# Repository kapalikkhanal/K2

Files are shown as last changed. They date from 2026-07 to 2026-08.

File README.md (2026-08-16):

# K2

A 3D-printed 12-DOF bipedal robot that **stands and marches in place** under a
reinforcement-learning policy, with a MuJoCo digital twin generated from the
Fusion 360 CAD export. A separate heading-aware policy provides low-speed
forward walking in the twin.

| | |
|---|---|
| DOF | 12 revolute — 6 per leg (hip pitch / roll / yaw, knee, ankle pitch / roll) |
| Actuators | 12× Feetech STS3215, 30 kg·cm @ 12 V (2.94 N·m, 4.712 rad/s) |
| Measured / modeled mass | 1.280 kg / 1.280 kg |
| Hip height (straight pose) | 336 mm |
| Foot-site stance width (straight pose) | 68 mm |
| Controller | Raspberry Pi 5 (policy inference 0.012 ms/tick on one CPU thread) |
| IMU | LSM6DS3, inside the electronics tray |
| Control rate | 50 Hz (2 ms physics × decimation 10) |

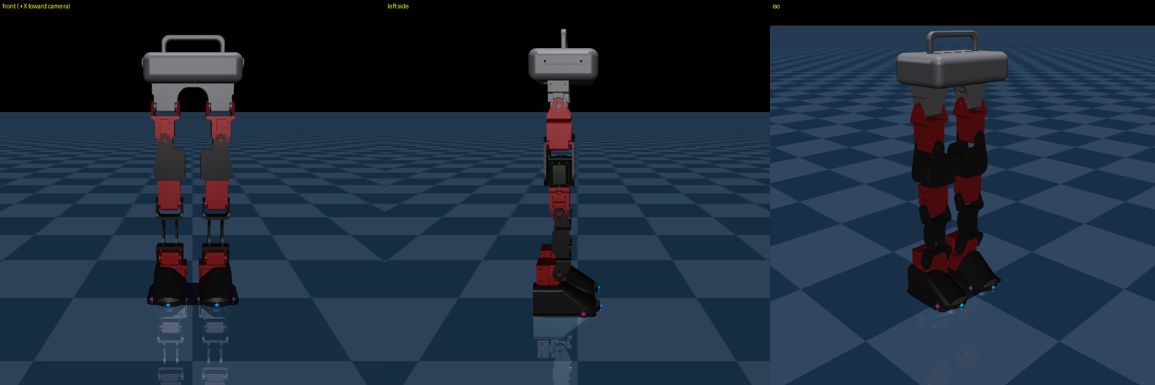
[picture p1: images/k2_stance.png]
K2 stance


## Scope

This repository covers **hold**, **march**, and a separate low-speed,
command-conditioned forward-walking task.

## Layout

```
k2_rl/            mjlab RL task: hold + march, PPO, ONNX export
hardware/         unified sim <-> real control stack (one code path)
policies/         trained policy, ready to deploy
mjcf/             MuJoCo model (generated)
urdf/             Fusion export + mass/limit-corrected URDF (generated)
meshes/K2/        visual .obj + convex collision .stl
scripts/          CAD -> URDF -> MJCF pipeline
docs/             link-to-link transformation matrices
robot.md          complete reference: joints, calibration, twin, deployment
```

Generated files are checked in, so the model and policy work without re-running
anything.

## Quick start

Run the trained policy in the twin:

```bash
python -m hardware.k2_policy_run --bus sim --viewer --mode march \
  --policy policies/march_hold_v4_1999.onnx

python -m hardware.k2_policy_run --bus sim --viewer --mode walk \
  --forward-speed 0.01 --policy policies/forward_walk_v1_iter950.onnx
```

On the real robot (from the Pi):

```bash
python -m hardware.k2_policy_run --bus /dev/ttyAMA0 --mode hold \
  --policy policies/march_hold_v4_1999.onnx
python -m hardware.k2_policy_run --bus /dev/ttyAMA0 --mode march \
  --march-after 5 --duration 20 --slew 1.0 --fall-angle 10 \
  --policy policies/march_hold_v4_1999.onnx --log run.csv
```

Torque release is retried and verified from every servo register on exit,
including Ctrl-C. `--slew` caps per-tick joint motion and `--fall-angle` cuts
torque above a torso tilt.

## Training

Needs [mjlab](https://github.com/mujocolab/mjlab) and a CUDA GPU.

```bash
python -m k2_rl.train Mjlab-InPlace-K2 --env.scene.num-envs 4096 \
  --agent.max-iterations 2000 --agent.run-name march_v4
python -m k2_rl.play  Mjlab-InPlace-K2       --checkpoint-file <run>/model_2000.pt
python -m k2_rl.play  Mjlab-InPlace-March-K2 --checkpoint-file <run>/model_2000.pt
python -m k2_rl.export_onnx --checkpoint <run>/model_2000.pt
```

Both task IDs share one checkpoint — the first plays it holding, the second
marching. `export_onnx` bakes the joint names, default pose and action scale
into the ONNX so the deploy script stays correct across retrains.

## The sim <-> real abstraction

The same program drives MuJoCo or the real servo chain by changing one flag.
The seam is the **servo bus, in raw encoder counts** — the robot's actual wire
language. Everything above it (calibration, count<->rad, observation building,
clamping, slew limiting, control rate) is identical code on both paths.

```bash
python -m hardware.k2_ctrl --bus sim --motion squat --viewer
python -m hardware.k2_ctrl --bus /dev/ttyAMA0 --motion squat
```

## Rebuilding the model from CAD

```bash
python scripts/phase1_mass.py       # -> urdf/K2_phase1.urdf
python scripts/phase2_make_mjcf.py  # -> mjcf/k2_physics.xml
python scripts/phase3_validate.py   # mass, limits, contact, torque
MUJOCO_GL=egl python scripts/render_check.py   # -> images/
python -c "from hardware import k2_conventions as C; C.write_joint_limits()"
```

## Conventions worth knowing before you change anything

- Robot faces world **+X**, **+Y is the robot's own LEFT**, **+Z** is up. This is
  forced: MuJoCo is right-handed, so with +x forward and +z up, +y is left.
- **The MJCF bodies named `*_right` sit at +y, i.e. on the robot's own LEFT.**
  Fusion named them from the viewer's side. `JOINT_TO_ID` accounts for this — read
  the leg-mapping note in `hardware/k2_conventions.py` before touching it.
- The IMU chip frame is not the root or MJCF `imu` site frame.
  `k2_attitude.py` uses the hardware-measured chip -> root -> site transforms;
  held forward/right tilts and a dynamic gyro/gravity consistency test validate
  the signs.
- Collision is **feet only**, so the legs cannot snag on their own shells.
- Timestep is **2 ms**. At 5 ms the foot-ground contact injects energy and the
  robot bounces higher than it was dropped from.
- Every hinge carries `armature=0.01` (STS3215 reflected rotor inertia). Without
  it the resting IMU reading chatters over [-1.8, 24.6] m/s^2 instead of 9.81.
- Joint limits are read from the MJCF into `hardware/joint_limits.json` — never
  hardcoded, so they cannot drift from the model.

## Status

Hold is solid. The calibrated march completed 27 continuous unsupported seconds
on hardware (after a 3 s hold), with a 12.54 deg exact logged peak against a
14 deg cutoff. The gait is stable but still has limited tilt margin and a
roughly 1.8 deg mean physical-left bias. Roll remains a geometric budget (stance
width vs CoM height), not merely a reward-tuning knob.

All five left/right sole reward sites now mirror within 0.001 mm. These sites do
not change collision geometry; their symmetry prevents the gait rewards from
teaching a lateral bias.

The forward-walk checkpoint `forward_walk_v1_iter950.onnx` is trained over
0.01--0.04 m/s with foam-compatible friction randomization. Nominal 20 s twin
tests produce 10.1--10.6 mm minimum full-sole swing clearance across that speed
range, no foot collisions, and at most 4.5 deg peak torso tilt. It has not yet
been validated unsupported on hardware.

See `robot.md` for the full reference and `k2_rl/README.md` for the task design.

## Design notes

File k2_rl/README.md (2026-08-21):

# k2_rl — RL locomotion for the K2 biped (mjlab)

Closed-loop RL locomotion for the 12-DOF K2. The original policy switches
between two behaviours **in place** (zero net translation):

- **hold** — stand still on both feet, stay upright, reject pushes (IMU feedback).
- **march** — step in place, alternating feet.

`Mjlab-Forward-K2` is a separate low-speed task. It retains hold/march balance
and adds a commanded forward speed in the initial 0.01--0.04 m/s range. Its
training randomizes sole height/angle, friction, actuator latency, and dynamics.

`Mjlab-Bidirectional-K2` is the conservative signed-speed successor. It trains
from scratch over -0.04--+0.04 m/s, keeps hold at the captured default crouch,
ramps both gait activation and velocity commands to prevent transition jerk,
and randomizes up to 5 mm unequal support, ±1.5° sole mounting, and light pushes.
Hold deliberately uses the previously proven learned support stance; it is not
forced into the narrower captured crouch because that variant fell in the twin.
The signed range is ±0.05 m/s, with a 0.8 s gait blend and 0.06 m/s² command
ramp for gentler hold/walk and forward/backward transitions.
Each gait begins at the v5 double-support crossing. Hold uses paired-joint
symmetry without forcing the exact default crouch, and walking hip-pitch
antisymmetry uses weight −4.

`Mjlab-Turn-K2` adds **one** thing to the bidirectional task: a commanded body
yaw rate. The command is `vx + wz` only -- there is no lateral (vy) channel.
Every term it changes is written so that with `wz == 0` it is *identical* to its
bidirectional predecessor, which is what makes warm-starting from a working
bidirectional checkpoint safe:

| bidirectional term | turning replacement | why |
|---|---|---|
| `base_heading_error` (world +X) | `heading_reference_error` | follow the *commanded* heading |
| `base_lateral_position_l2` (world +Y spawn line) | `lateral_path_deviation_l2` | corridor turns with the command |
| `base_yaw_rate_l2` (all yaw) | `yaw_rate_error_l2` | damp only yaw the command did not ask for |
| `track_angular_velocity` (twist, pinned to 0) | `track_yaw_rate_exp` | yaw target comes from the gait command |
| `heading_sin_cos` observation | `heading_error_sin_cos` | keep the feature near zero at any commanded yaw |
| `feet_lateral_vel_l2` (world Y) | `feet_lateral_vel_body_l2` | "sideways" is a body direction once you may turn |

`GaitCommand` integrates a **reference pose** (`heading_ref`, `pos_ref`) from the
commands it emits; those terms measure against it. With no yaw channel the
reference never rotates and never leaves the environment-origin line, so each
expression collapses to exactly its predecessor -- verified numerically to 0.0
max absolute difference. Deployment reproduces the same reference by integrating
the same emitted numbers, so this needs no extra sensing on the Pi.

Two further protections keep the straight gait from decaying: `rel_turning_envs`
gives 40% of resamples an exactly-zero yaw command (uniform sampling would make
straight walking measure-zero), and the hip-pitch antisymmetry penalty fades with
commanded yaw, because a turning gait is genuinely asymmetric. Hip-yaw pose
tolerance widens from 0.12 to 0.25 rad -- it is the steering joint; foot crossing
stays guarded by the unchanged inner-edge clearance and self-collision penalties.
Trained range is a deliberately conservative +/-0.25 rad/s with a 0.30 rad/s^2
command ramp.

`Mjlab-Full-K2` is isolated in `full_env_cfg.py`. It trains body-frame forward,
backward, left/right, and yaw-rate commands from scratch; it does not alter the
working forward-only policy interface.

The `march` bit is a per-episode command the policy observes (a fraction of envs
march, the rest hold), so a single trained policy does both — flip the bit at run
time. This is a closed balance-feedback loop: the policy reads the IMU every
tick and actively corrects lean and drift
(`robot.md` §10).

Built on mjlab's velocity-locomotion machinery, closely mirroring the Unitree G1
task (both are 6-DOF legs now), but written fresh — **never edit mjlab
site-packages**.

## Environment

Use the **`unitree_sim_env`** conda env (torch 2.7.0+cu128 with Blackwell/sm_120
GPU support + mjlab). The base env's torch does **not** support this GPU.

```bash
conda activate unitree_sim_env
cd ~/K2
```

## Package layout

| file | what |
|---|---|
| `k2_constants.py` | K2 `EntityCfg`: STS3215 position actuators (kp=20, kd=0.5 — same as `hardware/k2_bus.py`, so zero sim-to-real actuator gap), validated symmetric crouch keyframe, per-DOF regex patterns. |
| `mdp/gait_command.py` | `GaitCommand` — emits `[march, sin, cos]` plus optional signed forward speed and yaw rate, and integrates the reference pose those tasks measure against. |
| `mdp/rewards.py` | gait-aware rewards: `gait_contact`, `gait_swing`, `feet_planted`, `base_height_l2`. |
| `inplace_env_cfg.py` | the task: flat ground, zero-twist (stay in place), proprio-only actor obs (gyro + gravity + joints + gait — what the Pi can supply), domain randomization. |
| `forward_env_cfg.py` | 1--4 cm/s forward extension; heading feedback, foam-friction randomization, and full-sole swing clearance. |
| `bidir_env_cfg.py` | from-scratch -4--+4 cm/s forward/backward task with exact-crouch hold and smooth transitions. |
| `turn_env_cfg.py` | `vx + wz`: adds a +/-0.25 rad/s yaw-rate command to the bidirectional gait, measured against an integrated reference pose. |
| `expand_checkpoint.py` | widens a trained checkpoint by the appended command channels so it can be warm-started (zero weights, seeded normalizer, extended Adam moments). |
| `full_env_cfg.py` | robust omnidirectional task: ±4 cm/s x, ±2 cm/s y, and ±0.35 rad/s yaw. |
| `ppo_cfg.py` | PPO runner (MLP 256-128-64, 3000 iters). |
| `tasks.py` | registers the in-place hold/march pair plus the separate forward, bidirectional, turning, and full-locomotion tasks. |
| `validate_pose.py` | sanity-checks the default crouch stands (feet flat, symmetric, self-stable). |

The MJCF is the validated twin `mjcf/k2_physics.xml` (12 joints, feet-only
collision, IMU sensors). **Fusion naming gotcha:** joint names chain
`<parent>_<child>_…`, so `hip_pitch` also appears in the hip_roll joint name and
Always use the anchored patterns in `k2_constants.JOINT_PATTERNS`, never a
bare substring such as `.*hip_pitch.*`.

## Train

```bash
python -m k2_rl.train Mjlab-InPlace-K2 --env.scene.num-envs 4096 \
    --agent.max-iterations 3000 --agent.run-name inplace_v1

# Low-speed heading-aware forward walking (48-D actor observation).
python -m k2_rl.train Mjlab-Forward-K2 --env.scene.num-envs 4096 \
    --agent.max-iterations 2000 --agent.run-name forward_v1

# Forward/backward walking: train from scratch, with no --resume/load options.
conda run --no-capture-output -n unitree_sim_env \
  env MPLCONFIGDIR=/tmp/k2-mpl \
  python -m k2_rl.train Mjlab-Bidirectional-K2 \
    --env.scene.num-envs 4096 --agent.max-iterations 3000 \
    --agent.save-interval 100 --agent.run-name bidir_short_stride_v1

# Yaw turning: WARM-START from the working bidirectional checkpoint.
# Step 1 -- widen the checkpoint by the new command channel (48-D -> 49-D actor,
# 53-D -> 54-D critic). The new input column is ZERO, so the widened policy is
# numerically identical to the source until PPO learns to use it.
conda run --no-capture-output -n unitree_sim_env \
  python -m k2_rl.expand_checkpoint --task Mjlab-Turn-K2 \
    --checkpoint logs/rsl_rl/k2_bidir_v1/<run>/model_2700.pt
# -> logs/rsl_rl/k2_turn_v1/warmstart_<run>_model_2700/model_2700.pt
#
# Step 2 -- resume from it. --agent.max-iterations is ADDITIONAL iterations, and
# checkpoint numbering continues from the source (2700 -> 2700+N).
conda run --no-capture-output -n unitree_sim_env \
  env MPLCONFIGDIR=/tmp/k2-mpl \
  python -m k2_rl.train Mjlab-Turn-K2 --agent.resume True \
    --agent.load-run warmstart_<run>_model_2700 \
    --agent.load-checkpoint model_2700.pt \
    --env.scene.num-envs 4096 --agent.max-iterations 1500 \
    --agent.save-interval 100 --agent.run-name turn_v1_from_bidir_iter2700

# Full x/y/yaw locomotion (train from scratch; do not load a forward checkpoint).
python -m k2_rl.train Mjlab-Full-K2 --env.scene.num-envs 4096 \
    --agent.max-iterations 3000 --agent.run-name full_v1
```

Logs → `logs/rsl_rl/k2_inplace/<timestamp>_inplace_v1/`. An ONNX policy is
exported next to each checkpoint (`*.onnx`) for the Pi. TensorBoard:
`tensorboard --logdir logs/rsl_rl/k2_inplace`.

## Visualize a checkpoint (digital twin)

Point `--checkpoint-file` at a `model_*.pt` in the run dir. Native viewer:

```bash
RUN=logs/rsl_rl/k2_inplace/<timestamp>_inplace_v1

# HOLD (stand still, reject pushes)
python -m k2_rl.play Mjlab-InPlace-K2 --checkpoint-file $RUN/model_3000.pt

# MARCH in place (same policy, march bit forced on)
python -m k2_rl.play Mjlab-InPlace-March-K2 --checkpoint-file $RUN/model_3000.pt
```

Add `--viewer viser` to get a **Gait** dropdown (auto/hold/march) that switches
the behaviour live in the browser. `--num-envs 1` keeps it to a single robot.

## Export a checkpoint to policy.onnx

```bash
python -m k2_rl.export_onnx --task Mjlab-Forward-K2 \
    --checkpoint logs/.../model_950.pt --filename forward.onnx
```
Writes `policy.onnx` next to the checkpoint, with metadata (joint order,
stiffness/damping, default pose, `action_scale`, and gait frequency) baked in
for deployment. Forward-policy metadata also records its trained velocity range
instead of the fixed visualization command. The
`VelocityOnPolicyRunner` also auto-exports an onnx on every save, but that file
is overwritten each save — use `export_onnx` to pin a specific checkpoint.

## Run the ONNX over the Bus — twin then real (`hardware/k2_policy_run.py`)

Same code, sim or real; the runner rebuilds the policy's 45-D march, legacy
46-D forward, or heading-aware 48-D forward observation from IMU, integrated
relative yaw, joint feedback, phase clock, and known command.

```bash
P=logs/rsl_rl/k2_inplace/<ts>_inplace_v1/policy.onnx

# Digital twin (MuJoCo viewer, wall-clock):
python -m hardware.k2_policy_run --bus sim --viewer --mode hold  --policy $P
python -m hardware.k2_policy_run --bus sim --viewer --mode march --policy $P

# Forward policies only.
python -m hardware.k2_policy_run --bus sim --viewer --mode walk \
    --forward-speed 0.01 --policy policies/forward_walk_v1_iter950.onnx

# A bidirectional policy uses the same interface; negative means backward.
python -m hardware.k2_policy_run --bus sim --viewer --mode walk \
    --forward-speed -0.01 --policy policies/bidir_short_stride.onnx

# A turning policy adds --yaw-rate (rad/s, positive = left). It applies in
# mode=march (turn in place) and mode=walk (walk an arc), and is refused on a
# policy without a yaw channel.
python -m hardware.k2_policy_run --bus sim --viewer --mode walk \
    --forward-speed 0.02 --yaw-rate 0.15 --policy policies/turn_v1_iter<N>.onnx
python -m hardware.k2_policy_run --bus sim --viewer --mode march \
    --yaw-rate 0.20 --policy policies/turn_v1_iter<N>.onnx

# Real robot (Pi) — calibrate first, copy policy.onnx over, keep a hand near it:
python -m hardware.k2_policy_run --bus /dev/ttyAMA0 --mode hold  --policy $P --duration 15
python -m hardware.k2_policy_run --bus /dev/ttyAMA0 --mode march --march-after 3 --policy $P
python -m hardware.k2_policy_run --bus /dev/ttyAMA0 --mode walk \
    --forward-speed 0.01 --march-after 3 --duration 8 --fall-angle 10 \
    --policy policies/forward_walk_v1_iter950.onnx --log forward_walk_001.csv
```

The runner eases into the default crouch, then hands over to the policy; torque
is always released on exit (incl. Ctrl-C). `--slew RAD_S` caps per-tick joint
motion on hardware (default 1.0 rad/s, matching training); `--march-after S`
holds a few seconds before marching. The runner reads the training cadence from
the ONNX metadata; `--gait-freq` is only a diagnostic override. Start in
**hold**, spot the robot, then **march**.

The selected forward checkpoint measures 10.1--10.6 mm minimum clearance over
the entire sole at commands from 0.01 to 0.04 m/s in the nominal twin. Its first
hardware test must start at 0.01 m/s with the robot spotted; simulation results
are not an unsupported-hardware guarantee.
```

## Keyboard driving (`keyboard.py` twin, `real_keyboard.py` hardware)

Both run the real `hardware.k2_policy_run.run` path -- encoder quantization,
servo gains and limits, latency, ONNX Runtime -- so they exercise deployment
rather than the training viewer.

```
H  hold (also straightens the yaw command)   A  turn left    X  straighten
M  march in place                            D  turn right   Q  quit
W  walk forward     S  walk backward
```

A/D from HOLD start a turn in place. On a policy without a yaw channel A/D/X are
ignored and the turn keys are left out of the printed key list. `--yaw-rate` sets
the A/D magnitude (twin default 0.15 rad/s, hardware default 0.10 rad/s -- start
well below the trained maximum on the real robot).

## Observation sizes on the wire

| actor obs | policy | gait command |
|---|---|---|
| 45 | legacy in-place march | `[march, sin, cos]` |
| 46 | first forward | `+ vx` |
| 48 | heading-aware forward / bidirectional | `+ vx`, heading `[sin, cos]` |
| 49 | turning | `+ vx, wz`, heading is the ERROR `[sin, cos]` |

On a 49-D policy the heading channel is measured against a reference heading the
runner obtains by integrating the yaw rate it commanded itself, matching what
`GaitCommand` integrates in training. With no yaw command that reference stays at
zero and the channel is the plain relative heading, so 48-D policies are
unaffected -- verified by replaying `bidir_symmetric_swing12mm_iter2500.onnx`
through the updated runner with identical sole diagnostics.

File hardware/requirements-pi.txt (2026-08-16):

# Runtime packages not supplied by Raspberry Pi OS.
# The venv is created with --system-site-packages to reuse apt's numpy.
mujoco==3.6.0
feetech-servo-sdk==1.0.0
onnxruntime==1.27.0
smbus2==0.4.3
scipy==1.16.1

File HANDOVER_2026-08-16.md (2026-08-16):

# K2 Project Handover — 2026-08-16

This document is the current, self-contained project handover for the K2 biped. It records the repository state, physical robot, digital twin, calibration campaign, policy history, real-world tests, forward-walking work, robustness work, failure analysis, and the exact next actions. It is intentionally redundant with `README.md`, `robot.md`, and `k2_rl/README.md`: an engineer or another LLM should be able to begin here without relying on prior chat memory.

The user explicitly asked that work begin fresh from this repository and not from assumptions about older repositories. Treat the files and measurements named here as authoritative. Where this handover says a quantity is inferred or still unknown, do not silently promote it to a measurement.

## 1. Project objective and current outcome

K2 is a 12-DOF, 3D-printed biped driven by twelve Feetech STS3215 serial servos. The immediate progression is:

1. make hold and in-place marching reliable in MuJoCo and on the real robot;
2. make the MuJoCo model a useful digital twin of the assembled robot;
3. add low-speed forward walking without losing the stable marching behavior;
4. improve robustness to millimetre-scale floor unevenness and hardware variation;
5. later train a separate full command-conditioned policy for forward/backward, lateral, and yaw motion.

The first three objectives have materially succeeded. The calibrated real robot held stably, marched unsupported for a 30-second run (3 seconds hold followed by about 27 seconds marching), and subsequently walked forward using `forward_walk_v1_iter950.onnx`. The forward policy works on a truly flat floor and uses approximately 10–12 mm full-sole swing clearance. A small runtime balance trim improved a repeatable physical-left lean: +0.5 degrees `--balance-trim-right` extended one real walking trial from roughly 9.4 seconds to roughly 26.6 seconds before the safety cutoff.

The open problem is robustness. The working forward policy falls on even slightly uneven ground. A robustness fine-tune from checkpoint 950 is being trained using rough terrain, latency, friction, mass/inertia, gain, encoder, CoM, reset, and push randomization. A separate `full_env_cfg.py` has also been written but is not the policy currently being trained.

## 2. Repository and machine state

Local repository root:

```text
/home/rbbist.lab/K2
```

Training machine:

- laptop/workstation with an NVIDIA Blackwell 5000 Pro GPU;
- MuJoCo/mjlab is the active training stack;
- the required training environment is `unitree_sim_env` at `/home/rbbist.lab/miniconda3/envs/unitree_sim_env/bin/python`, with Torch 2.7.0+cu128 and Blackwell/sm_120 GPU support;
- CUDA/GPU access may require execution outside a restricted workspace sandbox;
- use `MPLCONFIGDIR=/tmp/k2-mpl` to avoid Matplotlib trying to write under a protected home config directory.

Real robot computer:

```text
host: pi@192.168.1.214
repository: /home/pi/K2
serial bus: /dev/ttyAMA0
```

The password supplied during bring-up was `raspberry`. Do not publish credentials in a public repository. SSH fingerprint setup and passwordless authentication are an operator/machine concern, not a policy or calibration artifact.

Important Git state at the time this report was started:

```text
HEAD: 4e63ad6 Working walking config
previous: 51d7a4d Marching working
```

The user pushed the working calibration/configuration to GitHub. Uncommitted work currently includes the robustness changes to `k2_rl/forward_env_cfg.py`, registration/PPO/documentation changes, and the new `k2_rl/full_env_cfg.py`. A deletion of `policies/forward_v1_iter200.onnx` was already present and must not be casually restored or overwritten; it may be the user's intentional cleanup. Always inspect `git status` and preserve unrelated user changes.

## 3. Physical robot

### 3.1 Mechanical structure

K2 has two six-DOF legs and no upper body. Per leg, the chain is:

```text
hip_pitch -> hip_roll -> hip_yaw -> knee -> ankle_pitch -> ankle_roll -> foot
```

The printed links are plain PLA. Each physical sole has or has been tested with a very thin foam sheet. This is important: policies that succeed by sliding a sole in low-friction simulation can stick on the foam in reality. The forward task therefore rewards true swing clearance and penalizes loaded-foot slip.

The robot is mechanically self-supporting in home and crouch poses because the geared servos resist back-driving. A robot appearing to “hold” with the policy enabled does not alone prove active balance; IMU response, command tracking, push recovery, and gait behavior are needed to distinguish active control from gearbox holding.

Fasteners, wiring, the Pi, and power electronics were not all explicit CAD components. The base mass was increased to include the Pi and power modules. Screws and wires were initially treated as small, but they matter through aggregate mass and, more importantly, CoM location and asymmetry. The assembled robot's measured total mass is **1.280 kg**. Individual link/component weights and a physical CoM measurement remain desirable future measurements.

### 3.2 Servos and power

- 12 × Feetech STS3215 serial-bus servos;
- nominal supply: 12 V;
- supply used: 12 V, 50 A SMPS with silicone wiring;
- Waveshare servo board with two physical output ports; six servos are connected to each port, but electrically/control-wise they form the expected serial bus configuration;
- servo capability modeled as 2.94 N·m stall torque and 4.712 rad/s no-load speed;
- encoder resolution is 4096 counts per revolution;
- goal counts are clamped to `[40, 4055]` to prevent single-turn wraparound.

The successful 30-second march reported a minimum measured bus voltage of 11.8 V at `ankle_roll_R` and no nonzero servo error samples. This does not look like a supply brownout. Temperature telemetry reported a maximum of 49 C and 121 rejected temperature outliers, while physical inspection did not indicate heating. Treat those temperature spikes as telemetry-quality issues unless independently confirmed; do not disable voltage/error monitoring.

### 3.3 IMU

The IMU is an LSM6DS3/LSM6-series device mounted at the location represented in the MJCF electronics tray. Its chip axes are not the root axes and are not the MuJoCo IMU site axes. The calibrated transformation is implemented in `hardware/k2_attitude.py` and the mounting-level correction is stored in `hardware/imu_level_calibration.json`.

The crucial measured mapping is:

```text
root_x = chip_y
root_y = -chip_x
root_z = chip_z
```

Held-forward, held-backward, held-right, stationary, and dynamic gyro-motion tests were performed. Before correction, physical forward/right tilts had inverted horizontal projected-gravity signs. After correction, the gyro/gravity consistency test achieved approximately 0.990 correlation and 1.004 gain over 369 moving samples. Stationary tilt after level calibration was approximately 0.028 degrees during the calibration test. Preserve this frame conversion; “simplifying” it back to raw chip axes will break closed-loop balance.

## 4. Coordinate, naming, and leg-mapping conventions

World/root convention:

```text
+X = robot forward
+Y = robot's own left
+Z = up
```

Fusion’s visual/body naming is misleading: MJCF bodies with `_right` are located at positive root Y, which is the physical robot’s left. The deployed mapping deliberately accounts for this. The policy/MJCF `_R` joint block drives physical servos 0–5, and `_L` drives physical servos 6–11 after the permanent mapping correction. Do not “fix” names based on appearance without redoing the matched-phase lift test.

This was a central calibration discovery. Symmetric crouches and isolated direction descriptions cannot reveal a left/right leg block swap because the checks are mirror-symmetric. The fault becomes obvious when the gait selects a support leg: before the mapping correction the physical first lift and torso shift disagreed with the twin. A diagnostic swapped one-lift then lifted the expected opposite foot. The swap was made permanent by changing the mapping and carrying each physical servo's zero/sign with it. The final mapping was validated over multiple lifts and a continuous march.

Fusion-generated joint names chain parent and child names. Consequently, `hip_pitch` is also a substring of the hip-roll joint name. Always use the anchored regular expressions in `k2_rl/k2_constants.py::JOINT_PATTERNS`; never use an unanchored expression like `.*hip_pitch.*`.

## 5. Authoritative calibration and poses

The important checked-in files are:

- `hardware/calibration.json`: per-joint `home_raw` and direction sign;
- `hardware/crouch_pose.json`: real/twin default crouch solution;
- `hardware/imu_level_calibration.json`: physical mounting-level correction;
- `hardware/joint_limits.json`: deployment joint limits derived from the model;
- `hardware/calibration_pre_manual_crouch_20260815.json`: pre-capture backup;
- `hardware/calibration_pre_permanent_legmap_20260815.json`: pre-leg-map backup.

The servo conversion is:

```text
q = sign * (raw - home_raw) * 2*pi/4096
raw = home_raw + sign * q * 4096/(2*pi)
```

Current `calibration.json` home counts, in policy order:

| Joint | Home raw | Sign |
|---|---:|---:|
| hip_pitch_R | 1750 | -1 |
| hip_roll_R | 3188 | -1 |
| hip_yaw_R | 1810 | -1 |
| knee_R | 2416 | -1 |
| ankle_pitch_R | 2526 | -1 |
| ankle_roll_R | 2335 | -1 |
| hip_pitch_L | 1913 | +1 |
| hip_roll_L | 2362 | +1 |
| hip_yaw_L | 2312 | +1 |
| knee_L | 2189 | +1 |
| ankle_pitch_L | 1804 | +1 |
| ankle_roll_L | 2017 | +1 |

The user manually placed the robot into the desired stable crouch and requested that pose be captured. The resulting model/default crouch is approximately:

```text
hip_pitch_R  -0.148999 rad
hip_roll_R    0
hip_yaw_R     0
knee_R       -0.610865 rad  (-35 deg)
ankle_pitch_R 0.461673 rad
ankle_roll_R  0

hip_pitch_L  -0.152870 rad
hip_roll_L    0
hip_yaw_L     0
knee_L       -0.610865 rad  (-35 deg)
ankle_pitch_L 0.458187 rad
ankle_roll_L  0
```

Solved base height is `0.300564 m`. The neutral base is shifted 10 mm backward (`neutral_base_shift_m = -0.01`) from the centered solution because the physical torso initially looked slightly rearward/uneven and this pose matched the stable real crouch. Calibration validation confirmed both knees bent evenly, both feet were flat, no visible lean, and no unusual servo sound.

Do not infer that a working march proves every calibration detail. The calibration is now considered complete because it was validated through pose, held tilt, dynamic IMU, selected-leg lift, telemetry lift, multi-step march, and an unsupported 30-second march—not merely because the robot could make a few motions.

## 6. Digital twin and model construction

Primary model: `mjcf/k2_physics.xml`.

The CAD-to-twin pipeline is:

```bash
python scripts/phase1_mass.py
python scripts/phase2_make_mjcf.py
python scripts/phase3_validate.py
MUJOCO_GL=egl python scripts/render_check.py
python -c "from hardware import k2_conventions as C; C.write_joint_limits()"
```

The original Fusion export assigned steel-like material mass and was far too heavy. The pipeline replaces link masses/inertias with print/hardware estimates, adds servo masses, and scales the resulting complete model to the measured assembled mass of 1.280 kg. Until component-by-component weights or a physical suspension/balance CoM measurement are available, the model preserves the CAD-derived relative distribution and uses CoM/inertia domain randomization during training.

Important simulation facts:

- physics timestep is 0.002 s;
- control decimation is 10, giving a 50 Hz policy/control rate;
- each hinge has `armature=0.01` to represent reflected rotor inertia and prevent contact chatter;
- only foot collision geometry is active, avoiding self-snagging printed shells;
- all five reward/diagnostic sites on each sole were mirrored to within 0.001 mm;
- the feet contain center, heel, toe, inner, and outer sites used for full-sole lift/flatness/clearance metrics;
- MuJoCo is currently sufficient; Isaac Sim is available but changing simulators does not solve an unidentified parameter/calibration gap by itself.

At 5 ms physics timestep, contact injected energy and the robot bounced unrealistically; retain 2 ms unless a full stability revalidation is performed. The policy loop remains 50 Hz.

### Making the twin closer to the real robot

The twin should not be made “perfect” by tuning a single nominal model until one log matches. A useful twin consists of a measured nominal model plus bounded distributions that include plausible real hardware. The current approach is:

1. exact total mass (1.280 kg);
2. measured geometry and joint axes/limits from CAD and hardware corrections;
3. exact captured home/crouch and permanent leg mapping;
4. correct IMU frame and level offset;
5. STS3215 torque/speed, PD gains, armature, rate, count quantization, target clamping, slew behavior, and command delay;
6. foam-compatible friction and full-sole contact behavior;
7. randomization of remaining uncertain properties rather than inventing precise values.

High-value future measurements are: individual assembled segment weights, physical CoM by balancing/suspension in multiple orientations, servo step-response under representative load, foam-floor static/dynamic friction, joint backlash/deadband, and repeated synchronized current/voltage/position logs. These should update both the nominal twin and randomization bounds.

## 7. Unified simulation/real control stack

`hardware/k2_policy_run.py` is the important deployment contract. The same high-level loop runs against `SimBus` or `SerialBus`; changing `--bus sim` to `--bus /dev/ttyAMA0` swaps only the bus implementation. Calibration, observation construction, count/radian conversion, policy inference, action scaling, joint limiting, slew limiting, approach behavior, logging, and safety logic are shared.

Core files:

| File | Role |
|---|---|
| `hardware/k2_conventions.py` | joint order, MJCF names, servo IDs, calibration conversions, limits |
| `hardware/k2_bus.py` | real STS bus and MuJoCo simulated bus |
| `hardware/k2_attitude.py` | simulation attitude and calibrated LSM6DS3 attitude |
| `hardware/k2_policy_run.py` | ONNX runner, observation, commands, safety, CSV telemetry |
| `hardware/k2_stabilizer.py` | unsafe tilt exception and bounded tilt handling |
| `hardware/k2_calibrate.py` | interactive servo calibration |
| `hardware/check_joint_signs.py` | physical sign verification |
| `hardware/capture_home.py` | captures raw home counts |
| `hardware/calibrate_imu_level.py` | stationary mounting correction |
| `hardware/k2_imu_motion_test.py` | dynamic gyro/gravity frame validation |
| `hardware/test_default_crouch.py` | safe approach and crouch hold check |

Safety behaviors in the runner:

- cosine/eased approach from current physical position into policy default pose;
- IMU fall cutoff armed during approach and policy execution;
- target slew limit, normally 1.0 rad/s;
- joint-limit and raw-count clamps;
- torque release on normal exit, exception, unsafe tilt, and Ctrl-C;
- telemetry and 50 Hz CSV logging;
- on real hardware, always spot the robot and begin with a short duration.

The ONNX model metadata is authoritative for joint names/order, default joint pose, action scale, gait frequency, checkpoint iteration, neutral base shift, gait command dimension, and heading observation dimension. Do not manually copy these values into a new runner.

Supported deployed observation layouts are:

```text
45-D legacy march:
  gyro(3), projected gravity(3), q-default(12), qdot(12),
  last raw action(12), gait(3)

46-D early forward:
  the above plus commanded forward velocity in gait(4)

48-D heading-aware forward:
  gyro(3), projected gravity(3), q-default(12), qdot(12),
  last raw action(12), relative heading sin/cos(2), gait+vx(4)
```

Relative heading is integrated from gyro at runtime and exists to oppose gradual yaw/lateral drift without requiring unavailable global localization.

## 8. Calibration and hardware-validation chronology

The bring-up sequence is worth preserving because it explains why the current mappings are trustworthy.

1. The robot was manually leveled and brought to a symmetric crouch. Both knees bent evenly, soles were flat, the torso did not visibly lean, and no unusual noises were heard.
2. Hold was tested, with the caveat that servo gearing can make passive holding look successful.
3. A single-lift policy test initially lifted the robot's physical right leg first. The torso shifted toward the physical left support side, but the exact phase/leg agreement with the twin was suspect.
4. The desired crouch was captured from the physical robot rather than forcing an older nominal pose.
5. Held forward/back/right IMU tests exposed the frame/sign mismatch. The chip-to-root-to-site conversion and level calibration were corrected.
6. A dynamic gyro motion test validated the corrected transform.
7. After IMU correction, a one-lift test improved but still indicated that policy leg blocks were mapped across the physical robot.
8. A temporary swapped one-lift lifted the opposite physical leg as predicted. This isolated the leg-map problem rather than a joint-direction problem.
9. The leg mapping was made permanent while preserving each physical servo's captured home/sign.
10. Telemetry lift and final validation were run. The final calibration march used a 12-degree cutoff and performed several lifts without the earlier divergent side fall.
11. The user pushed the calibration state to GitHub.
12. A later unsupported 30-second march with a 14-degree cutoff completed all 1500 ticks at 50.0 Hz.

Local calibration logs include:

```text
crouch_real_01.csv
hold_real_01.csv
march_one_lift_01.csv
hold_after_crouch_capture_01.csv
march_one_lift_after_capture_01.csv
hold_after_imu_fix_01.csv
march_one_lift_after_imu_fix_01.csv
march_one_lift_swapped_01.csv
march_one_lift_telemetry_01.csv
march_final_calibration_01.csv
march_stable_30s.csv
```

Do not delete these; they document causal calibration changes.

## 9. March policy and real result

Working march policy:

```text
policies/march_hold_v4_1999.onnx
checkpoint: 1999
gait frequency: 0.75 Hz
action scale: 0.2 rad
neutral base shift: -10 mm
control: 50 Hz
```

Digital twin command:

```bash
python -m hardware.k2_policy_run --bus sim --viewer --mode march \
  --policy policies/march_hold_v4_1999.onnx
```

Successful physical command:

```bash
cd /home/pi/K2
.venv/bin/python -m hardware.k2_policy_run \
  --bus /dev/ttyAMA0 --mode march \
  --march-after 3 --duration 30 --approach 3 \
  --slew 1.0 --fall-angle 14 \
  --policy policies/march_hold_v4_1999.onnx --yes
```

The run held for the first three seconds and marched to 30 seconds. Tilt during marching was typically about 5–9 degrees, with periodic peaks around 11–12.2 degrees. The exact reported values included peaks at 12.2 degrees while remaining below the 14-degree safety threshold. Worst tracking RMS was `knee_L` at 3.78 degrees and worst peak error was also `knee_L` at 8.54 degrees. Minimum voltage was 11.8 V, maximum reported temperature 49 C, and servo error samples were zero.

The robot was unsupported and had no rope attached. It showed a small physical-left torso bias, estimated visually around 2–3 degrees during some phases, but did not fall. It also produced tiny net steps instead of perfect in-place marching, motivating the explicit commanded-forward policy rather than simply increasing the march action.

## 10. Forward-walking policy development

The forward task lives in `k2_rl/forward_env_cfg.py` and is registered as `Mjlab-Forward-K2`. It extends the proven march task rather than rewriting the whole locomotion environment.

Working selected checkpoint:

```text
training run:
logs/rsl_rl/k2_forward_v1/2026-08-15_23-06-47_forward_heading_clearance11_v6/

PyTorch checkpoint:
model_950.pt

deployed ONNX:
policies/forward_walk_v1_iter950.onnx
```

The forward command training range is 0.01–0.04 m/s. The working physical test used 0.01 m/s. The gait remains 0.75 Hz and action scale remains 0.2 rad. The task added observable forward speed and relative-heading sin/cos, while replacing in-place translation penalties with forward tracking plus strong lateral drift/heading/yaw shaping.

The initial forward behavior exploited sliding. Because the real foam sole stuck to the floor, the swing target was raised. `FORWARD_SWING_HEIGHT = 0.015 m` is a shaped target; the learned nominal policy achieves about 73% of it, producing measured full-sole clearance around 10.1–10.6 mm in the digital twin across the 0.01–0.04 m/s command range. The task tracks all sole sites, rewards phase-correct swing/contact, penalizes planted-foot slip, and penalizes a tilted swing sole.

Nominal real test command:

```bash
cd /home/pi/K2
.venv/bin/python -m hardware.k2_policy_run \
  --bus /dev/ttyAMA0 --mode walk --forward-speed 0.01 \
  --march-after 3 --duration 20 --approach 3 \
  --slew 1.0 --fall-angle 16 \
  --policy policies/forward_walk_v1_iter950.onnx \
  --log forward_walk_v1_iter950_001.csv --yes
```

The user confirmed it walks. The persistent issue was a physical-left lean. The runtime option `--balance-trim-right` applies a small virtual roll correction to the policy's gravity observation; positive values request support correction toward robot-right. A +0.5-degree right trim substantially improved the trial duration (approximately 9.4 s to 26.6 s before left-tilt cutoff). This is a calibrated compensating trim, not proof that the nominal model CoM is exact. Keep it available for current hardware tests, but train CoM/encoder asymmetry robustness so future policies need less trimming.

## 11. Forward-only robustness configuration

The current robustness edit deliberately preserves the successful forward gait, observations, and reward values. It changes the training distribution only.

Production training retains the original validated flat plane. Heightfields, adjacent box grids, and even a generated continuous slope all produced rare MuJoCo-Warp NaNs in long 2048-environment runs. Uneven support is therefore represented through per-environment sole-geometry randomization: the left and right sole collision geoms independently receive ±1.5 mm vertical offset and ±1 degree roll/pitch mounting error. This creates up to 3 mm unequal support and direct sole/floor angular mismatch without entering the unstable terrain-generator collision path.

Additional current randomization:

- foot friction: 0.7–1.4, shared by the two sole geoms;
- validated randomized substep action latency: 0–10 ms;
- pseudo-inertia: ±15% on massive robot links only;
- stiffness and damping scales: 0.8–1.2;
- encoder/home bias: ±0.02 rad;
- base CoM offset: x/y ±10 mm, z ±20 mm;
- moderate pushes every 3–5 s: translation and roll/pitch up to ±0.18, yaw up to ±0.25;
- reset yaw restricted to ±0.08 rad for a world-X forward/lateral-corridor task.

The base task already included the validated dynamics randomization above. Robustness training adds continuous slope variation, foam-compatible friction, and measured command latency while keeping the learned gait definition unchanged. Earlier attempts widened every dynamics range simultaneously; those combinations were removed because rare physics divergence prevented useful long training.

### Numerical-instability investigation

Three production attempts using the initially wider randomization failed before the first new checkpoint:

```text
forward_robust_rough_latency_v7     4096 envs, failed around iteration 968
forward_robust_rough_latency_v7b    2048 envs, failed around iteration 955
forward_robust_rough_latency_v7c    2048 envs, failed around iteration 960
```

Short diagnostics succeeded:

- 64 environments for 20 updates;
- 2048 environments for 20 updates (`diagnose_large`).

Therefore the config parsed, ran, and optimized, but a rare long-horizon environment diverged. MuJoCo/mjlab NaN guarding isolated environment 1059 at environment step 3085. The diagnostic files are outside the repository:

```text
/tmp/mjlab/nan_dumps/nan_dump_20260816_071723.npz
/tmp/mjlab/nan_dumps/nan_dump_latest.npz
/tmp/mjlab/nan_dumps/model_20260816_071723.mjb
```

The rolling 100-step physics-state history was finite immediately before each detected NaN, implying sudden contact divergence. Tightening `-25%` inertia / `0.55x` stiffness and doubling CCD did not cure it. A box-grid run saved checkpoint 1000 then failed around 1007; a continuous-slope run failed around 1086; removing the experimental whole-step latency queue still failed around 1030. Diffing the exact successful checkpoint-950 environment snapshot showed the terrain generator was the only substantive remaining difference. Production `v14` therefore uses the validated plane plus per-environment sole height/angle randomization. It passed checkpoints 1100 and 1200 with full-length episodes and zero falls/collapses. NaN guarding remains enabled.

Do not accept a checkpoint merely because one exists: verify that training reached it without NaN, inspect reward/episode length and termination trends, then replay it on flat and rough digital-twin terrain before exporting for hardware.

## 12. Active robustness training and monitoring

The production fine-tune targets iteration 2450 and saves every 100 iterations. It uses 2048 environments in `unitree_sim_env`. Resume semantics are important: `--agent.max-iterations` means additional iterations. `forward_robust_sole_dr_v14` was manually stopped at the user's request after safely writing `model_1600.pt`. It passed checkpoints 1100 through 1600 without a NaN. No trainer process remained after shutdown. To reach iteration 2450, resume `model_1600.pt` for 850 additional iterations under a new run name.

Exact launch command:

```bash
cd /home/rbbist.lab/K2
conda run --no-capture-output -n unitree_sim_env \
  env MPLCONFIGDIR=/tmp/k2-mpl \
  python -m k2_rl.train Mjlab-Forward-K2 \
  --env.scene.num-envs 2048 \
  --env.sim.nan-guard.enabled True \
  --agent.resume True \
  --agent.load-run 2026-08-16_07-36-15_forward_robust_sole_dr_v14 \
  --agent.load-checkpoint model_1600.pt \
  --agent.max-iterations 850 \
  --agent.save-interval 100 \
  --agent.run-name forward_robust_sole_dr_v15
```

Expected checkpoint sequence is `model_1000.pt`, `model_1100.pt`, ..., `model_2400.pt`, plus whatever final save behavior the runner applies at 2450. Monitoring at each 100-iteration checkpoint should record:

1. checkpoint path and wall time;
2. whether the process is alive and free of NaN/tracebacks;
3. mean reward;
4. mean episode length;
5. important termination counts (`fell_over`, `collapsed`, time-out if reported);
6. forward tracking, gait swing/contact, slip, base tilt, heading/lateral penalties;
7. learning rate, KL, policy noise/std, value loss, and surrogate loss;
8. whether metrics trend catastrophically away from the checkpoint-950 behavior.

After a promising checkpoint is produced, run nominal flat replay first. Then test generated rough terrain or a controlled disturbance in simulation. Only after passing simulation should it be explicitly exported with `k2_rl.export_onnx` and copied to the Pi under a new filename. Never overwrite `forward_walk_v1_iter950.onnx`; it is the rollback policy.

## 13. Full locomotion configuration

`k2_rl/full_env_cfg.py` is a separate task registered as `Mjlab-Full-K2`. It was created by using the working forward design as a baseline, but it is not a fine-tune target for the forward checkpoint because its command and observation semantics differ.

Training commands are body-frame:

```text
vx:  -0.04 to +0.04 m/s
vy:  -0.02 to +0.02 m/s
wz:  -0.35 to +0.35 rad/s
```

Ten percent of training environments receive standing commands. Moving commands use the alternating gait clock. The actor sees the three-component twist command immediately before the gait observation. Heading is not included because yaw-rate control should remain rotation-invariant and should not depend on long-term gyro-integrated yaw.

The task removes zero-translation/zero-yaw penalties that would fight its commands, widens hip roll/yaw/ankle-roll pose tolerance, and retains full-sole lift/contact/slip/flatness shaping and the same terrain/randomization concept. It should train from scratch:

```bash
python -m k2_rl.train Mjlab-Full-K2 \
  --env.scene.num-envs 4096 \
  --agent.max-iterations 3000 \
  --agent.run-name full_v1
```

Before beginning a long full-locomotion run, copy the long-horizon stability correction from the forward config into `full_env_cfg.py`: avoid the already-observed `-25% inertia / 0.55x stiffness` corner. Then perform 20-update and at least 100-update diagnostics with NaN guarding. The full policy also needs deployment runner support for its twist-command observation before any real test; current `k2_policy_run.py` explicitly supports the 45/46/48-D march/forward layouts, not an arbitrary full-locomotion observation.

## 14. PPO and training architecture

`k2_rl/ppo_cfg.py` defines separate experiment names while sharing the PPO architecture:

- actor MLP: 256, 128, 64, ELU;
- critic MLP: 256, 128, 64, ELU;
- actor and critic observation normalization enabled;
- Gaussian action distribution, scalar initial standard deviation 1.0;
- clipped PPO value loss coefficient 1.0;
- policy clip 0.2;
- entropy coefficient 0.01;
- 5 learning epochs, 4 minibatches;
- adaptive learning rate starting at 1e-3;
- gamma 0.99, lambda 0.95;
- desired KL 0.01;
- gradient norm clamp 1.0;
- 24 steps per environment per PPO update.

Experiment directories:

```text
logs/rsl_rl/k2_march_v4/
logs/rsl_rl/k2_forward_v1/
logs/rsl_rl/k2_full_v1/
```

The runner automatically exports an ONNX at saves, but its generic `policy.onnx` may be overwritten. Use the explicit exporter to pin a selected checkpoint:

```bash
python -m k2_rl.export_onnx \
  --task Mjlab-Forward-K2 \
  --checkpoint logs/rsl_rl/k2_forward_v1/<run>/model_<iteration>.pt \
  --filename forward_robust_iter<iteration>.onnx
```

## 15. Simulation validation before hardware

For every candidate robustness checkpoint:

1. replay at `0.01 m/s`, because this is the already-tested physical command;
2. replay at 0.02, 0.03, and 0.04 m/s to check the full trained range;
3. measure full-sole minimum apex clearance, sole height spread, inner-edge gap, and foot-to-foot collision contacts;
4. verify heading and lateral drift over at least 30 seconds;
5. verify it can recover from moderate pushes without exaggerated side lift;
6. verify nominal flat performance was not destroyed by roughness optimization;
7. compare action magnitude and joint speeds against checkpoint 950;
8. reject any candidate with simulation NaNs or unexplained contact explosions.

Example nominal twin command after export:

```bash
python -m hardware.k2_policy_run \
  --bus sim --viewer --mode walk --forward-speed 0.01 \
  --duration 30 --fall-angle 16 \
  --policy policies/forward_robust_iterXXXX.onnx \
  --log robust_sim_iterXXXX_001.csv
```

Because `hardware.k2_policy_run --bus sim` uses the nominal MJCF, it is not sufficient by itself to validate rough-terrain robustness. Also use the mjlab play environment/config or a controlled generated-terrain evaluation. The nominal bus replay is still valuable because it exactly exercises deployment observation and action code.

## 16. Safe real-robot evaluation protocol

Only test real hardware after a candidate passes the preceding checks. Preserve checkpoint 950 as the fallback.

1. Put the robot on the flattest surface first, with a human spotter holding close without loading the body.
2. Verify the calibrated crouch and stationary IMU tilt.
3. Run hold for a short duration.
4. Run a one-lift/very short walk with conservative cutoff.
5. Run 8–10 seconds at 0.01 m/s on flat ground.
6. Increase to 20–30 seconds only if tracking, voltage, tilt, and sound are normal.
7. Apply the known `--balance-trim-right 0.5` initially if using the same physical assembly and direction convention, but also compare an untrimmed logged run.
8. Test unevenness progressively: 1–2 mm controlled shim/texture before arbitrary floor seams. Never jump directly to aggressive rough ground.
9. Save every CSV with policy iteration, command, trim, surface, and trial number in the filename.

Template command:

```bash
cd /home/pi/K2
.venv/bin/python -m hardware.k2_policy_run \
  --bus /dev/ttyAMA0 --mode walk --forward-speed 0.01 \
  --march-after 3 --duration 10 --approach 3 \
  --slew 1.0 --fall-angle 12 \
  --balance-trim-right 0.5 \
  --policy policies/forward_robust_iterXXXX.onnx \
  --log forward_robust_iterXXXX_flat_001.csv --yes
```

If the robot consistently leans left again, do not immediately increase trim. Compare commanded/measured ankle roll, hip roll, knee tracking, stationary projected gravity, initial base pose, and per-side load/current. A consistent lean may be a CoM offset, calibration bias, compliance, foam asymmetry, or servo response mismatch. The trim is a safe small compensation, not a substitute for diagnosis.

## 17. Known risks and unresolved questions

1. **Physical CoM is not directly measured.** Total mass is measured, but distribution is estimated. CoM randomization helps but does not identify the nominal offset.
2. **Individual component weights are incomplete.** A scale capable of measuring links/components would improve inertia and CoM estimates.
3. **Servo temperature telemetry has rejected outliers.** Physical heating was not observed, but the sensor/read path deserves validation.
4. **Loaded servo bandwidth differs from simulation.** March logs show knee RMS errors around 3.7–3.8 degrees and peaks around 8.5 degrees.
5. **The current forward policy has a small physical-left bias.** Runtime trim helps. Robustness training should cover plausible lateral CoM/encoder/gain asymmetry.
6. **Rough-terrain physics can become numerically unstable under overly aggressive parameter combinations.** NaN guard is mandatory during long diagnostics.
7. **Full locomotion is only a config/smoke-tested task.** It is not trained, exported, or supported by the real runner yet.
8. **The repository documentation contains a few historical measurements.** Prefer current checked-in JSON/model values and this dated handover when numbers conflict; update older prose when committing.
9. **A mechanically held pose can mask weak active control.** Validate feedback dynamically.
10. **A symmetric pose can mask a left/right leg mapping error.** Validate with phase-selected single lifts.

## 18. Exact continuation checklist

For the current operator/LLM:

- [ ] Keep the `forward_robust_stable_v8` process alive and monitor every 100 iterations.
- [ ] Confirm `model_1000.pt` is created without NaN before assuming the stability fix worked.
- [ ] At each checkpoint record concise metrics in this report or a sibling training log.
- [ ] If NaN recurs, retain the dump; isolate terrain/contact versus gain/CoM/push by ablation rather than lowering all randomization blindly.
- [ ] When training finishes, rank candidate checkpoints using rough and nominal simulation, not final iteration alone.
- [ ] Explicitly export the selected checkpoint under a new ONNX filename.
- [ ] Copy only the new policy and required code/config updates to `/home/pi/K2`; preserve calibration JSON.
- [ ] Test flat ground first with spotting, low speed, short duration, and a conservative cutoff.
- [ ] Save the real CSV locally and compare with checkpoint 950.
- [ ] Commit the robustness config, full config, documentation, and selected policy only after validation; do not commit temporary dumps or huge training logs unless intentionally desired.

For improving the twin later:

- [ ] measure individual assembled link/component masses;
- [ ] perform a physical CoM balance/suspension measurement in at least two orientations;
- [ ] identify loaded servo step response, deadband, and backlash;
- [ ] estimate foam-floor friction;
- [ ] verify per-leg mechanical symmetry and fastener tightness;
- [ ] update nominal parameters, then narrow randomization around measurements rather than removing it.

## 19. Command quick reference

```bash
# Digital twin: working march
python -m hardware.k2_policy_run --bus sim --viewer --mode march \
  --policy policies/march_hold_v4_1999.onnx

# Digital twin: working forward policy
python -m hardware.k2_policy_run --bus sim --viewer --mode walk \
  --forward-speed 0.01 \
  --policy policies/forward_walk_v1_iter950.onnx

# Real march, known successful structure
cd /home/pi/K2
.venv/bin/python -m hardware.k2_policy_run \
  --bus /dev/ttyAMA0 --mode march --march-after 3 \
  --duration 30 --approach 3 --slew 1.0 --fall-angle 14 \
  --policy policies/march_hold_v4_1999.onnx --yes

# Real forward, known working policy
.venv/bin/python -m hardware.k2_policy_run \
  --bus /dev/ttyAMA0 --mode walk --forward-speed 0.01 \
  --march-after 3 --duration 20 --approach 3 \
  --slew 1.0 --fall-angle 16 --balance-trim-right 0.5 \
  --policy policies/forward_walk_v1_iter950.onnx \
  --log forward_walk_v1_iter950_trim05_001.csv --yes

# Robustness fine-tune from checkpoint 950
conda run --no-capture-output -n unitree_sim_env \
  env MPLCONFIGDIR=/tmp/k2-mpl \
  python -m k2_rl.train Mjlab-Forward-K2 \
  --env.scene.num-envs 2048 --env.sim.nan-guard.enabled True \
  --agent.resume True \
  --agent.load-run 2026-08-16_07-36-15_forward_robust_sole_dr_v14 \
  --agent.load-checkpoint model_1600.pt \
  --agent.max-iterations 850 --agent.save-interval 100 \
  --agent.run-name forward_robust_sole_dr_v15

# Full locomotion from scratch, after long-horizon DR correction
python -m k2_rl.train Mjlab-Full-K2 \
  --env.scene.num-envs 4096 --agent.max-iterations 3000 \
  --agent.run-name full_v1
```

## 20. Final state statement

The project is no longer at “the robot barely moves.” It has a calibrated sim-to-real path, a measured-mass MuJoCo twin, a verified IMU transform, a verified permanent leg map, an unsupported stable march, and a working low-speed forward policy. The current engineering task is controlled robustness expansion while preserving the checkpoint-950 flat-ground behavior. The greatest danger is changing gait/reward/calibration and domain randomization simultaneously; keep the working policy and calibration as fixed rollback anchors, change uncertainty coverage deliberately, and validate each candidate in simulation before asking the physical robot to prove it.

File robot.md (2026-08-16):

# K2 — 12-DOF Biped Robot: Complete Reference

A self-contained knowledge dump for the K2 biped: the hardware, the
digital twin, the software stack, the calibration, the RL task, and how to
deploy it. Written so another engineer or LLM can pick up with full context.

Repo root: `~/K2`. Intended to be **open-sourced**, so keep it clean — only
files that are strictly needed.

---

## 1. What K2 is

K2 is a small **12-DOF bipedal robot** (two 6-DOF legs, no upper body). It was
designed in Fusion 360 (current export: **Robot_v4**, 2026-07) and is developed
**digital-twin-first**: every change is validated in a MuJoCo model before it
touches hardware, and the *same control code* drives sim or the real robot by
changing one flag.

- **Total mass:** **1280 g measured and modeled**. Link masses/inertias are
  uniformly scaled by 1.086034, preserving the CAD CoM until physical CoM data
  is available; training still randomizes the base CoM.
- **Standing hip height:** ~364 mm; standing base-link height ~335 mm; CoM ~194 mm
- **Nominal stance width:** feet at ±55–58 mm (≈110–116 mm apart)
- **Controller:** Raspberry Pi 5 (see §9)

### Leg structure (per leg, hip → toe)
`hip_pitch → hip_roll → hip_yaw → knee → ankle_pitch → ankle_roll`, mirrored L/R.
The v4 redesign added the **ankle_roll** DOF (a second ankle servo per leg); the
ankle-roll link (`Feet`) is the foot plate that carries the sole. This DOF is
what makes **static single-foot support** possible (lateral CoM shift), which is
the mechanical prerequisite for a stable slow walk.

### Links (13)
`base_link`, and per side (`_left`/`_right`): `Hip_pitch`, `Hip_roll`,
`Hip_yaw`, `Knee`, `Ankle` (the ankle-pitch bracket), `Feet` (the ankle-roll
foot plate — **the sole/collision lives here**, not on `Ankle`).

---

## 2. Joints, axes, limits

Short name → MJCF joint name (note Fusion's odd auto-labels — keep exact spelling,
including the misspelled "anke" and the word "pitch" inside the *roll* joint):

| short | MJCF joint name | axis | limit (deg) |
|---|---|---|---|
| hip_pitch_R/L | `base_link_hip_pitch_{right,left}_joint` | pitch (world Y) | ±47 |
| hip_roll_R/L | `hip_pitch_hip_roll_{right,left}_joint` | roll (world X) | R [−45,+22], L [−22,+45] |
| hip_yaw_R/L | `hip_roll_hip_yaw_{right,left}_joint` | yaw (world Z) | ±45 |
| knee_R/L | `hip_yaw_knee_{right,left}_joint` | pitch (world Y) | **[−110, 0] both** |
| ankle_pitch_R/L | `knee_ankle_pitch_{right,left}_joint` | pitch (world Y) | ±30 |
| ankle_roll_R/L | `ankle_roll_foot_{right,left}_joint` | roll (world X) | **[−20, +40]** |

Key sign/limit facts (learned the hard way):
- **Both knees flex NEGATIVE** on v3/v4 (both ranges `[−110°, 0]`). The Fusion
  export ships the knee limit sign-inverted on *every* re-export — always fix it.
- **hip_roll is asymmetric**: ~45° abduction (leg out) vs ~22° adduction (leg in,
  tuck under body). Adduction is the tight side.
- **ankle_roll is asymmetric**: **~20° inversion (inward, sole faces in)** vs
  **~50° eversion (outward)**. The inward/inversion direction is what a lateral
  weight-shift needs, so **12–20° inward is the binding limit** for balance.
  (Started at 12° — a bracket interference — mechanically opened to 20° on
  2026-07-22. Update `ANKLE_ROLL_IN` in `scripts/phase1_mass.py` if it changes.)
- The world axes above are verified from the MJCF, not assumed. `+q` on
  `ankle_roll` drops the foot's **inner edge** (toward the other foot); `+q` on
  `ankle_pitch` lifts the toe (dorsiflex).

---

## 3. Actuators & bus

- **12× Feetech STS3215** (serial bus servos), 12 V. **2.94 N·m stall**
  (30 kg·cm), **4.712 rad/s** no-load (45 rpm), **60 g each**. Single-turn
  encoder, **0–4095 counts/rev**.
- One **serial bus**, Waveshare adapter (CH343 USB-serial, `1a86:55d3`) at
  **`/dev/ttyACM0`, 1 Mbps**. SDK: `feetech-servo-sdk` (module `scservo_sdk`),
  **PacketHandler protocol_end = 0** for STS.
- Registers: ID **5**, Baud **6**, HomingOffset **31**, TorqueEnable **40**,
  GoalPos **42**, Lock **55**, PresentPos **56**, PresentSpeed **58**
  (sign-magnitude, bit15 = direction).
- **Goal counts are hard-clamped to [40, 4055]** everywhere (never let a goal
  wrap past 0/4095 — the single-turn servo would take the long way round).
- **Port gotcha:** `/dev/ttyACM0` resets to non-writable on every replug.
  Fix each time: `sudo chmod 666 /dev/ttyACM0` (or add user to `dialout`).

### Servo ID map — chain 0..11, both ankle-rolls at the ends
Physical chain: physical-left foot (0) up to its hip (5), across to the
physical-right hip (6), down to its foot (11).

**The MJCF's `_R` joints drive physical-left servos 0..5 and `_L` drives
physical-right servos 6..11.** Fusion's `*_right` bodies sit at +root-Y, which
is the robot's physical left. This mapping was re-established from fresh
matched-phase tests on 2026-08-15: it selected the correct swing foot and made
real roll/pitch signs match MuJoCo. `calibration.json` was swapped with the map
so every physical servo retained its captured zero and sign. Change both
together or neither.

None of the held-air sign checks can catch a leg swap: every `POS_DESC` string is
mirror-symmetric ("outward", "pigeon-toed", "toe up"), so all 12 joints pass on
either leg, and a symmetric crouch is invariant under mirroring. It only shows up
once the gait has to pick a leg to shift weight onto.

**ID 0 is valid** and works through the SDK. The map lives in
`k2_conventions.JOINT_TO_ID` — the single source of truth; everything reads it.
Assign/renumber with `python -m hardware.set_servo_id --scan | --from N --to M`
(one servo at a time).

---

## 4. Calibration

Maps servo counts ↔ joint radians, per joint:

```
q = sign * (raw - home_raw) * 2π/4096
raw = home_raw + sign * q * 4096/2π
```

- `home_raw` = the encoder count at the **straight pose** (q = 0). **Sign-flips
  do NOT change the home pose** — at q=0 every servo goes to `home_raw` regardless
  of sign. So a "leaning at home" problem is always a *home* issue, never a sign.
- `sign` = ±1, the direction the joint moves for +q. Stored in
  `hardware/calibration.json`. Sim uses an identity calibration by construction,
  so miscalibration can only ever come from hardware.
- `sign` = ±1, the direction the joint moves for +q. All 12 were re-verified on
  hardware with `check_joint_signs.py` (hips, knees and all four ankles, both
  directions). After the leg swap the entries read +1 for every `_R` joint and −1
  for every `_L` joint, because each servo kept the sign measured on it.

### How to (re)calibrate — `python -m hardware.k2_calibrate` (GUI, needs DISPLAY)
1. LIMP (torque off), hand-pose the robot dead straight with **both feet flat**.
2. Capture HOME (records `home_raw`). *A leaning stand at "home" = a foot wasn't
   flat / a joint wasn't straight when captured — re-capture, don't flip signs.*
3. Nudge each joint, Flip any whose motion disagrees with its description, Save.
4. Go to CROUCH to validate.

**Debugging lesson:** single-joint direction checks can be *misjudged* (a whole
leg swinging is easy to read wrong). The reliable test is the **single-leg crouch
mirror comparison** (crouch each leg alone; they must be mirror images). And
remember: **home offsets are masked when both feet are planted** (the floor
constrains them) and only show up when a foot is **free** (swing / one-foot
balance). That is why a robot can crouch cleanly but fail during a step.

---

## 5. Digital twin (MuJoCo / MJCF)

Model file: `mjcf/k2_physics.xml`. Built by a 3-phase pipeline in `scripts/`:

1. **`phase1_mass.py`** — rebuilds link masses/inertia from *measured* print
   weights (Fusion tags every link "Steel" → ~4× too heavy) and adds STS3215
   point masses (60 g/joint) via parallel-axis; overrides the placeholder joint
   limits with the real ones. Writes `urdf/K2_phase1.urdf`.
   - Per-link PLA (g): base 30 (shell) + 70 (electronics point mass, 6 cm up);
     hip_pitch 16, hip_roll 25, hip_yaw 14, knee 27, ankle_pitch 22, Feet 14.
2. **`phase2_make_mjcf.py`** — URDF → MJCF, fixing what URDF can't express.
3. **`phase3_validate.py`** — drops it on a vertical slide with temp servos to
   check feet contact / no tunnelling / holding torque.

### MJCF conventions (non-obvious, will recur on any Fusion→MuJoCo biped)
- **Floating base:** a URDF root compiles into a *fixed* base. Inject a `world`
  link + `type="floating"` joint, then nest the tree under a world-aligned root
  body `k2_root` (carries the free joint) so the base frame is Z-up.
- **Y-up → Z-up:** Fusion is Y-up. Don't rotate every link — give `base_link`
  the `0.5 0.5 0.5 0.5` quat inside `k2_root`.
- **`discardvisual="false"`** in a `<mujoco>` block inside the URDF, or MuJoCo
  throws away visual geoms and leaves only collision hulls.
- **Feet-only collision** on the `Feet_*` bodies (so legs can't self-snag). Foot
  sole/site positions are **measured from the collision mesh**, never hardcoded.
- **Timestep 2 ms** (5 ms injects contact energy and the robot bounces higher
  than it was dropped). Decimate ×10 for a 50 Hz control loop.
- **`armature=0.01`** on every hinge (reflected rotor inertia; without it the
  foot contact chatters and resting IMU accel swings wildly).
- **IMU site + sensors** on `base_link`: `imu_ang_vel` (gyro), `imu_lin_vel`
  (velocimeter), `imu_lin_acc` (accelerometer), `imu_quat` (framequat),
  `root_angmom` (subtreeangmom). Foot sites `right_foot`/`left_foot`
  (+ heel/toe) with framepos/framelinvel sensors. **The shipped MJCF has NO
  actuators** — mjlab (training) and SimBus (direct control) add them.

---

## 6. Software stack — `~/K2/hardware/` (unified sim ↔ real)

The whole point: **the same program drives MuJoCo or the real servo chain** by
changing one flag. The abstraction sits at the **servo bus, in raw encoder
counts** — the robot's real wire language. Everything above it (calibration,
count↔rad, observation building, clamping, slew-limiting, control rate) is
byte-identical on both paths.

```
python -m hardware.k2_ctrl --bus sim --motion squat --viewer
python -m hardware.k2_ctrl --bus /dev/ttyACM0 --motion squat
```

Core modules:
- **`k2_conventions.py`** — the hub. `SIM_ORDER` (right leg hip→toe, then left),
  `JOINT_TO_ID`, `JOINT_TO_MJCF`, `POS_DESC`/`NUDGE_DIR` (calibration help),
  count↔rad math, calibration load/save. **Joint limits are read from the MJCF**
  (`write_joint_limits()` → `joint_limits.json`) — never hardcoded, so they can't
  drift from the model. The Pi loads the small JSON (no MuJoCo needed).
- **`k2_bus.py`** — `Bus` ABC + `SerialBus` (real STS3215) + `SimBus` (MuJoCo).
  Interface: `tick(dt)` / `read_pos_speed()` / `write_goals()` / `torque(on)`.
  SimBus quantises to 12-bit counts and clamps [40,4055] so the policy sees
  hardware-grade resolution; it adds position servos force-limited to 2.94 N·m.
- **`k2_ctrl.py`** — the control loop. Eases from the robot's *current* pose into
  the start pose, slew-limited, and **always releases torque on exit incl.
  Ctrl-C** (goes limp, never freezes). Modes: `squat`, `hold`.
- **`k2_calibrate.py`** — 12-servo calibration GUI (see §4).
- **`k2_motion.py`** — `SquatIK`, a flat-foot double-support squat solved against
  the MJCF (needs no IMU: both planted feet close the chain).
- **`k2_policy_run.py`** — runs a trained ONNX policy over the `Bus`, sim or
  real, one code path. Rebuilds the legacy 45-D march observation, 46-D initial
  forward observation, or 48-D heading-aware forward observation byte-for-byte;
  reads joint order / default pose / action scale from ONNX metadata and clamps
  joint targets.
- **`k2_attitude.py`** — `SimAttitude` (MuJoCo ground truth) and `ImuAttitude`
  (LSM6DS3 + adaptive complementary filter), one interface. Returns
  `(gyro, projected_gravity)`. **The gyro is returned in the MJCF `imu` SITE
  frame**, not the chip frame — see §9.
- **`k2_stabilizer.py`** — `UnsafeTiltError` and bounded tilt feedback.
- **`test_default_crouch.py`** — eases into the model-derived default crouch and
  holds it, with an IMU tilt cutoff. The first thing to run after calibrating.
- **`check_joint_signs.py`** — verifies any subset of the 12 calibration signs,
  both directions, held in air. Supersedes the old per-group scripts.
- **`capture_home.py`** — snapshots the pose the robot is standing in right now
  into `calibration.json` `home_raw`, working purely in raw counts.
- **`go_home.py`**, **`set_servo_gain.py`**, **`set_servo_id.py`**,
  **`calibrate_imu_level.py`** (IMU mounting-tilt calibration).

Config files (checked in): `calibration.json`, `joint_limits.json`,
`crouch_pose.json` (the default crouch), `imu_level_calibration.json`.

---

## 7. Deploying a trained policy

`hardware/k2_policy_run.py` runs the ONNX over the same `Bus`, so the twin and
the robot execute identical code.

```bash
# twin
python -m hardware.k2_policy_run --bus sim --viewer --mode march \
  --policy policies/march_hold_v4_1999.onnx
# real
python -m hardware.k2_policy_run --bus /dev/ttyAMA0 --mode march \
  --march-after 5 --duration 20 --slew 1.0 --fall-angle 10 \
  --policy policies/march_hold_v4_1999.onnx --log run.csv
```

The legacy 45-D observation is rebuilt exactly as the march env built it:

```
[ base_ang_vel(3)      gyro, MJCF imu SITE frame
  projected_gravity(3) gravity direction, k2_root frame
  joint_pos_rel(12)    q - default_pose, SIM_ORDER
  joint_vel_rel(12)    qdot, SIM_ORDER
  last_action(12)      previous RAW policy output
  gait(3) ]            [march, march*sin(phase), march*cos(phase)]
```

Targets are `default_pose + action_scale * action`, clamped to the joint limits
and to counts [40, 4055]. Joint order, default pose, action scale and gait
frequency all come from the ONNX metadata, so a retrain cannot silently break
the deploy path.

**Safety:** torque is released on every exit path including Ctrl-C; `--slew`
caps per-tick joint motion; `--fall-angle` cuts torque above a torso tilt; the
robot is eased into the default crouch over `--approach` seconds before the
policy takes over, with the tilt cutoff already armed.

`--log` writes a 50 Hz CSV of commanded vs measured position for all 12 joints
plus gyro, gravity, tilt and raw actions. **This log is the single most useful
debugging artifact** — a mis-mapped joint tracks its command perfectly while the
IMU response is orthogonal to what that command should produce.

---

## 8. Where the real robot currently stands

- All 12 servos calibrated; all 12 signs verified on hardware with
  `check_joint_signs.py`, both directions.
- IMU mounting tilt calibrated (`calibrate_imu_level.py`); the gyro frame bug in
  §9 is fixed.
- **Permanent leg mapping validated** (§3); no deployment flag is required.
- **Hold is solid**, settling near 0.7 deg tilt with no drift.
- **March validation passed** for four continuous seconds (about six lifts) at
  50 Hz with a 10.82 deg logged peak against a 12 deg cutoff. Minimum dynamic
  servo voltage was 11.9 V and post-run temperatures were 35--39 C.
- Dynamic command tracking remains less accurate than the twin: worst final-run
  knee RMS/peak error was 3.71/8.51 deg. Actuator bandwidth identification is
  still a sim-to-real task.
- **Twin update (2026-08-15):** modeled mass now matches 1.280 kg and all five
  left/right sole reward sites mirror within 0.001 mm. A separate low-speed
  forward task uses a fourth gait command channel plus integrated relative-yaw
  feedback. Its selected checkpoint (`forward_walk_v1_iter950.onnx`) measures
  10.1--10.6 mm full-sole clearance at 0.01--0.04 m/s in nominal simulation;
  real forward walking remains unvalidated.

---

## 9. Controller: Raspberry Pi 5 (not Jetson)

Benchmarked the policy MLP at **0.012 ms/inference** on a single Pi 5 CPU thread
(~0.06% of a 50 Hz budget). GPU is only for *training* or vision models. The Pi 5
is lighter/lower-power (better on `base_link`) and its I2C/SPI eases the IMU. A
Jetson would only be justified if cameras / a VLA are added later.

IMU on the Pi: **LSM6DS3**, inside the electronics tray.

**The chip frame is not the root or MJCF `imu` site frame.** Fresh held tests on
2026-08-15 found both horizontal projected-gravity axes inverted: physical
forward reported -12.5 deg pitch and physical right reported +12.8 deg roll.
The measured mounting transform is now `root_x=chip_y`, `root_y=-chip_x`,
`root_z=chip_z`; level calibration then reduced stationary tilt to 0.028 deg.

`k2_attitude.py` maps chip -> root for gravity and chip -> root -> site for the
policy gyro. `k2_imu_motion_test.py` validates the frame-invariant relationship
`gravity_dot = -omega x gravity`; the corrected hardware measured correlation
0.990 and gain 1.004 over 369 moving samples.

---

## 10. The RL task — `k2_rl/`

Built fresh on mjlab's velocity machinery (never edit mjlab site-packages).
**One policy, two behaviours:** `GaitCommand` emits `[march, sin, cos]`; a
fraction of envs march each episode and the policy observes the bit, so the same
network holds still or steps in place depending on one runtime flag.

- Actor observations are **proprio-only** — gyro, projected gravity, joint
  pos/vel, last action, gait command. No base linear velocity, because the IMU
  velocimeter is not trustworthy on hardware. This is exactly what the Pi can
  supply.
- Actuators are modelled as STS3215 position servos with **kp=20 / kd=0.5, the
  same values `hardware/k2_bus.py` uses**, so the actuator sim-to-real gap is
  zero by construction.
- Domain randomization covers the gaps chased during bring-up: pseudo-inertia
  +-15%, foot friction 0.4-1.1, PD gains x0.8-1.2, encoder bias +-0.02 rad
  (home/calibration offset), base CoM offset, control latency, random pushes.
- Default pose is a symmetric standing crouch that is self-stable under kp/kd.

**Two gotchas that will recur:**
1. **Fusion chained joint names** — `hip_pitch` is a substring of the hip_roll
   joint name. Use the parent-anchored regexes in `k2_constants.JOINT_PATTERNS`,
   never a bare `.*hip_pitch.*`.
2. **`dr.pseudo_inertia` on `.*` bodies crashes** (cholesky "not positive
   definite") because it perturbs the massless free-joint carrier. Target only
   the massive links.

Reward tip: use quadratic penalties for "keep X near a target"; exp-kernel
rewards with small std go flat and give no gradient at large error.

---

## 11. Recurring Fusion-export bugs (expect on every re-export)
1. Every link tagged `Steel` (7850 kg/m³) → ~4× too heavy. Rescale per-link to
   measured print weight, add hardware point masses.
2. **Knee limits sign-inverted.**
3. `effort=100, velocity=1.0` placeholders → real STS3215 2.94 N·m / 4.712 rad/s.
4. Fusion is **Y-up**.
Joint/link names may also change between exports (e.g. lose Fusion `_2`/`_3`
suffixes) — grep for stale references after any re-export.

---

## 12. Quick command reference

```bash
cd ~/K2
# rebuild the twin after a CAD/limit change:
python scripts/phase1_mass.py && python scripts/phase2_make_mjcf.py
python -c "from hardware import k2_conventions as C; C.write_joint_limits()"

# hardware bring-up:
python -m hardware.set_servo_id --port /dev/ttyAMA0 --scan
DISPLAY=:1 python -m hardware.k2_calibrate                  # calibrate (GUI)
python -m hardware.check_joint_signs --joints all --amp 10  # verify signs, held in air
python -m hardware.calibrate_imu_level                      # IMU mounting tilt
python -m hardware.go_home --bus /dev/ttyAMA0               # ease to straight home

# validate, then run the policy (sim first, then real):
python -m hardware.test_default_crouch --bus sim --viewer
python -m hardware.k2_policy_run --bus sim --viewer --mode march \
  --policy policies/march_hold_v4_1999.onnx
python -m hardware.k2_policy_run --bus /dev/ttyAMA0 --mode hold \
  --policy policies/march_hold_v4_1999.onnx
```

Ctrl-C always drops the robot limp. On the real robot start slow, keep a hand
near it, and always run `--mode hold` before `--mode march`.

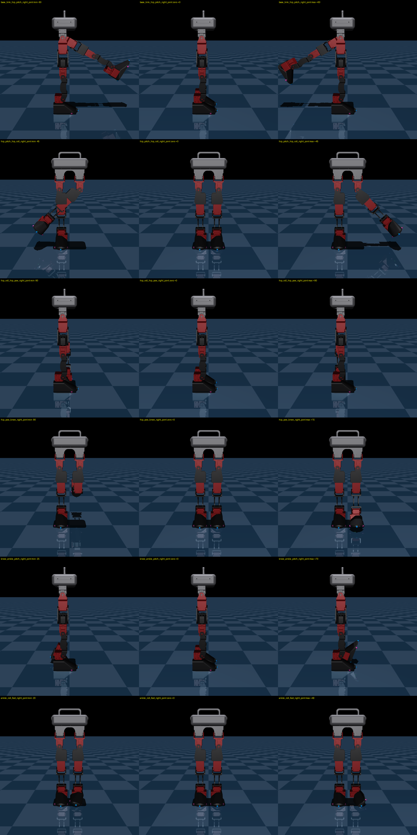
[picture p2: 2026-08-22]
images/k2_joints_right.png

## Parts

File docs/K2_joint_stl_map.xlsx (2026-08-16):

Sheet: Joint ↔ STL
Obs idx | Short name | Servo ID | Side | MJCF joint name | URDF joint name | Parent link | Child link (moved by this joint) | Child collision STL | Child visual OBJ | MJCF mass (kg) [authoritative] | URDF mass (kg) [stale] | MJCF axis | URDF axis | Limit lo (deg) | Limit hi (deg) | home_raw | sign | Positive direction moves… | OK?
0 | hip_pitch_R | 6 | R | base_link_hip_pitch_right_joint | base_link_hip_pitch_right_joint | base_link | hip_pitch_right | Hip_pitch_right_collision.stl | Hip_pitch_right.obj | 0.0747 | 0.470867 | 1 0 0 | 1.000000 -0.000000 0.000000 | -60 | 60 | 1917 | 1 | right foot swings BACKWARD
1 | hip_roll_R | 7 | R | hip_pitch_hip_roll_right_joint | hip_pitch_hip_roll_right_joint | Hip_pitch_right | hip_roll_right | Hip_roll_right_collision.stl | Hip_roll_right.obj | 0.085 | 0.567771 | 0 0 1 | -0.000000 0.000000 -1.000000 | -45 | 45 | 2347 | 1 | right foot swings OUTWARD, away from the left leg
2 | hip_yaw_R | 8 | R | hip_roll_hip_yaw_right_joint | hip_roll_hip_yaw_right_joint | Hip_roll_right | hip_yaw_right | Hip_yaw_right_collision.stl | Hip_yaw_right.obj | 0.0701 | 0.400297 | 0 -1 0 | -0.000000 -1.000000 -0.000000 | -90 | 90 | 2312 | 1 | right TOE rotates INWARD (pigeon-toed)
3 | knee_R | 9 | R | hip_yaw_knee_right_joint | hip_yaw_knee_right_joint | Hip_yaw_right | Knee_right | Knee_right_collision.stl | Knee_right.obj | 0.087 | 0.212616 | -1 0 0 | -1.000000 -0.000000 -0.000000 | -90 | 0 | 2193 | 1 | right knee BENDS (heel rises relative to toe)
4 | ankle_pitch_R | 10 | R | knee_ankle_pitch_right_joint | knee_ankle_pitch_right_joint | Knee_right | ankle_right | Ankle_right_collision.stl | Ankle_right.obj | 0.082 | 0.650099 | -1 0 0 | -1.000000 -0.000000 -0.000000 | -25 | 70 | 1801 | 1 | right TOE tilts UP (dorsiflex), heel drops
5 | ankle_roll_R | 11 | R | ankle_roll_foot_right_joint | anke_roll_ankle_pitch_right_joint | Ankle_right | Feet_right | Feet_right_collision.stl | Feet_right.obj | 0.074 | 0.398908 | 0 0 1 | -0.000000 0.000000 1.000000 | -20 | 40 | 1995 | 1 | right foot's OUTER edge LIFTS, inner edge (toward the left foot) DROPS
6 | hip_pitch_L | 5 | L | base_link_hip_pitch_left_joint | base_link_hip_pitch_left_joint | base_link | hip_pitch_left | Hip_pitch_left_collision.stl | Hip_pitch_left.obj | 0.0747 | 0.470867 | -1 0 0 | -1.000000 0.000000 0.000000 | -60 | 60 | 1697 | -1 | left foot swings BACKWARD
7 | hip_roll_L | 4 | L | hip_pitch_hip_roll_left_joint | hip_pitch_hip_roll_left_joint | Hip_pitch_left | hip_roll_left | Hip_roll_left_collision.stl | Hip_roll_left.obj | 0.085 | 0.567771 | 0 0 1 | 0.000000 -0.000000 -1.000000 | -45 | 45 | 3155 | -1 | left foot swings OUTWARD, away from the right leg
8 | hip_yaw_L | 3 | L | hip_roll_hip_yaw_left_joint | hip_roll_hip_yaw_left_joint | Hip_roll_left | hip_yaw_left | Hip_yaw_left_collision.stl | Hip_yaw_left.obj | 0.0701 | 0.400297 | 0 1 0 | 0.000000 1.000000 -0.000000 | -90 | 90 | 1813 | -1 | left TOE rotates INWARD (pigeon-toed)
9 | knee_L | 2 | L | hip_yaw_knee_left_joint | hip_yaw_knee_left_joint | Hip_yaw_left | Knee_left | Knee_left_collision.stl | Knee_left.obj | 0.087 | 0.212616 | 1 0 0 | 1.000000 0.000000 -0.000000 | -90 | 0 | 2326 | -1 | left knee BENDS (heel rises relative to toe)
10 | ankle_pitch_L | 1 | L | knee_ankle_pitch_left_joint | knee_ankle_pitch_left_joint | Knee_left | ankle_left | Ankle_left_collision.stl | Ankle_left.obj | 0.082 | 0.6501 | 1 0 0 | 1.000000 0.000000 -0.000000 | -25 | 70 | 2555 | -1 | left TOE tilts UP (dorsiflex), heel drops
11 | ankle_roll_L | 0 | L | ankle_roll_foot_left_joint | anke_roll_ankle_pitch_left_joint | Ankle_left | Feet_left | Feet_left_collision.stl | Feet_left.obj | 0.074 | 0.398908 | 0 0 1 | 0.000000 -0.000000 1.000000 | -20 | 40 | 2386 | -1 | left foot's OUTER edge LIFTS, inner edge (toward the right foot) DROPS

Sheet: Meshes
Link / body | Driven by joint (short) | Collision STL | STL size (KB) | Triangles | BBox X (mm) | BBox Y (mm) | BBox Z (mm) | Visual OBJ | MJCF mass (kg) | URDF mass (kg) | CoM xyz (m)
base_link | — (floating base) | base_link_collision.stl | 16.6 | 338 | 154.02 | 119.26 | 99 | base_link.obj | 0.233 | 1.196448 | 0.027914 0.011270 0.003243
Hip_pitch_right | hip_pitch_R | Hip_pitch_right_collision.stl | 13 | 264 | 45.4 | 74.64 | 37.8 | Hip_pitch_right.obj | 0.0747 | 0.470867 | -0.007803 -0.027041 0.000209
Hip_pitch_left | hip_pitch_L | Hip_pitch_left_collision.stl | 12.9 | 262 | 45.4 | 74.64 | 37.8 | Hip_pitch_left.obj | 0.0747 | 0.470867 | -0.007803 -0.027041 -0.000209
Hip_roll_right | hip_roll_R | Hip_roll_right_collision.stl | 10.7 | 218 | 50.82 | 74.14 | 45.2 | Hip_roll_right.obj | 0.085 | 0.567771 | 0.042246 0.009959 0.018837
Hip_roll_left | hip_roll_L | Hip_roll_left_collision.stl | 10.7 | 218 | 50.82 | 74.14 | 45.2 | Hip_roll_left.obj | 0.085 | 0.567771 | 0.042246 0.009959 -0.018837
Hip_yaw_right | hip_yaw_R | Hip_yaw_right_collision.stl | 8.8 | 178 | 38.37 | 50.76 | 29.92 | Hip_yaw_right.obj | 0.0701 | 0.400297 | 0.010788 -0.045739 0.000504
Hip_yaw_left | hip_yaw_L | Hip_yaw_left_collision.stl | 8.7 | 176 | 38.37 | 50.76 | 29.92 | Hip_yaw_left.obj | 0.0701 | 0.400297 | 0.010788 -0.045739 -0.000504
Knee_right | knee_R | Knee_right_collision.stl | 21.4 | 436 | 45.4 | 114.13 | 30.2 | Knee_right.obj | 0.087 | 0.212616 | 0.018769 -0.047347 0.003932
Knee_left | knee_L | Knee_left_collision.stl | 20.7 | 422 | 45.4 | 114.13 | 30.2 | Knee_left.obj | 0.087 | 0.212616 | 0.018769 -0.047347 -0.003932
Ankle_right | ankle_pitch_R | Ankle_right_collision.stl | 9 | 182 | 47.73 | 56.87 | 45.74 | Ankle_right.obj | 0.082 | 0.650099 | -0.021076 0.015301 -0.014103
Ankle_left | ankle_pitch_L | Ankle_left_collision.stl | 8.7 | 176 | 47.73 | 56.87 | 45.74 | Ankle_left.obj | 0.082 | 0.6501 | -0.021076 0.015301 0.014103
Feet_right | ankle_roll_R | Feet_right_collision.stl | 17.7 | 360 | 55.2 | 42 | 105.11 | Feet_right.obj | 0.074 | 0.398908 | -0.007940 -0.023198 0.001344
Feet_left | ankle_roll_L | Feet_left_collision.stl | 19.4 | 396 | 55.2 | 42 | 105.11 | Feet_left.obj | 0.074 | 0.398908 | -0.007940 -0.023198 -0.001344
TOTAL |  |  |  |  |  |  |  |  | 1.1786 | 6.5976

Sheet: Notes & discrepancies
Topic | What to watch for when verifying
Sources | Joint axes/limits + body tree: mjcf/k2_physics.xml. Masses, parent/child, URDF joint names: urdf/K2_fusion_export.urdf. Servo IDs, home_raw, sign: hardware/k2_conventions.py + hardware/calibration.json. Triangle counts and bounding boxes read from the STL files.
Mesh scale | Every mesh is referenced with scale="0.01 0.01 0.01". The STLs are in centimetre units; bounding boxes in the Meshes sheet already have that scale applied and are shown in mm.
MASS: URDF is stale | The URDF and MJCF masses disagree by about 5.6x on every link (URDF total 6.598 kg vs MJCF total 1.179 kg). The URDF is a raw Fusion export with a default material density applied to solid bodies; the MJCF carries the real measured/estimated masses and is what sim and the policies actually use. Verify against the MJCF column — the URDF column is shown greyed out only so the gap is visible. Do not regenerate the MJCF inertials from this URDF.
Joint-name mismatch | The ankle-roll joint is called ankle_roll_foot_{left,right}_joint in the MJCF but anke_roll_ankle_pitch_{left,right}_joint in the URDF (note the 'anke' typo from the Fusion export). Rows are matched by CHILD LINK, not by name, so the table is still correct.
Limit mismatch | joint_limits.json caps both knees at 0.0 upper even though the MJCF/CAD allows +0.2618 rad (15 deg past straight). That is deliberate — locomotion must not command the hyperextended branch. The URDF's own limits also differ from the MJCF on several joints; the MJCF is authoritative for sim and hardware.
Left/right naming | The MJCF's right_* bodies sit at +y, which is the robot's own LEFT. The legs were swapped in JOINT_TO_ID on 2026-07-28 (proven on hardware): MJCF _R joints drive servos 6..11 and _L drives 0..5. Do not 'fix' the servo map from mesh names alone.
Sign checks are mirror-blind | Every POS_DESC phrase is mirror-symmetric ('outward', 'pigeon-toed', 'toe up'), so a held-air check confirms each joint's axis and sign but can never catch a left/right swap. Verify side assignment by moving ONE servo ID at a time and watching which physical leg responds.
Chain order | Servo IDs form a daisy-chain: one foot (0) up to that hip (5), across to the other hip (6), down to that foot (11). If a rewire changes the chain, this sheet must be regenerated.
Regenerate | python -m scripts.make_joint_stl_sheet (from the repo root)

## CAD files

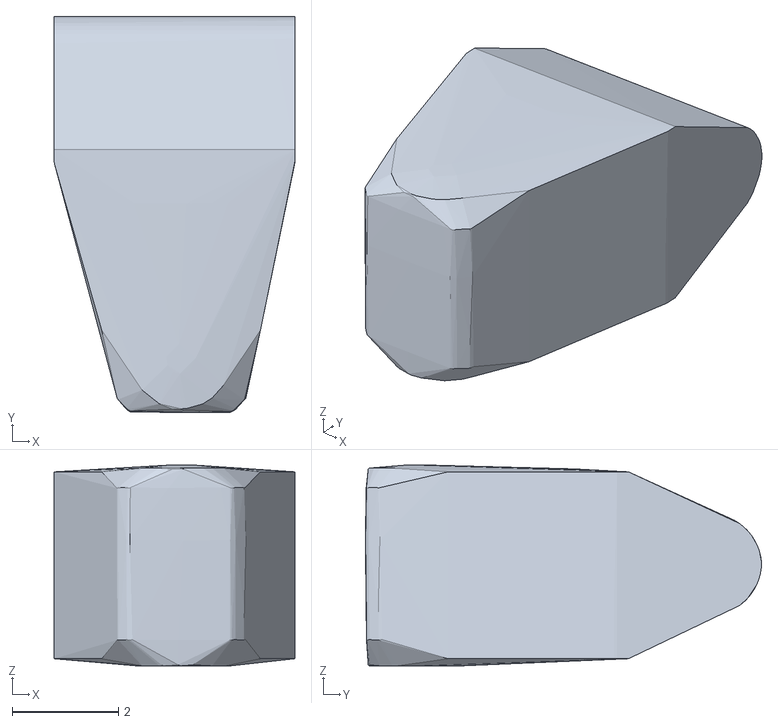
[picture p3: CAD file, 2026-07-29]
meshes/K2/Hip_pitch_left_collision.stl
4.54 x 7.46 x 3.78

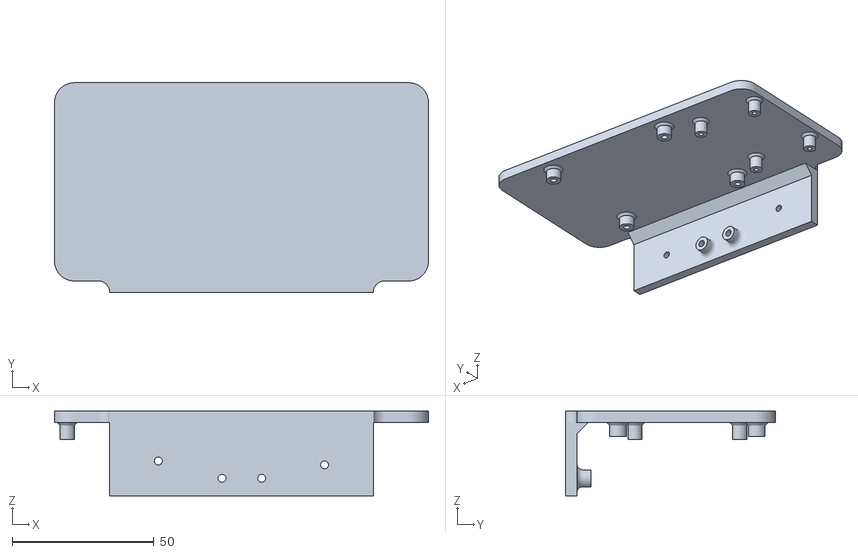
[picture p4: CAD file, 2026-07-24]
stl/Pi_Holder.obj
132.0 x 74.0 x 29.9

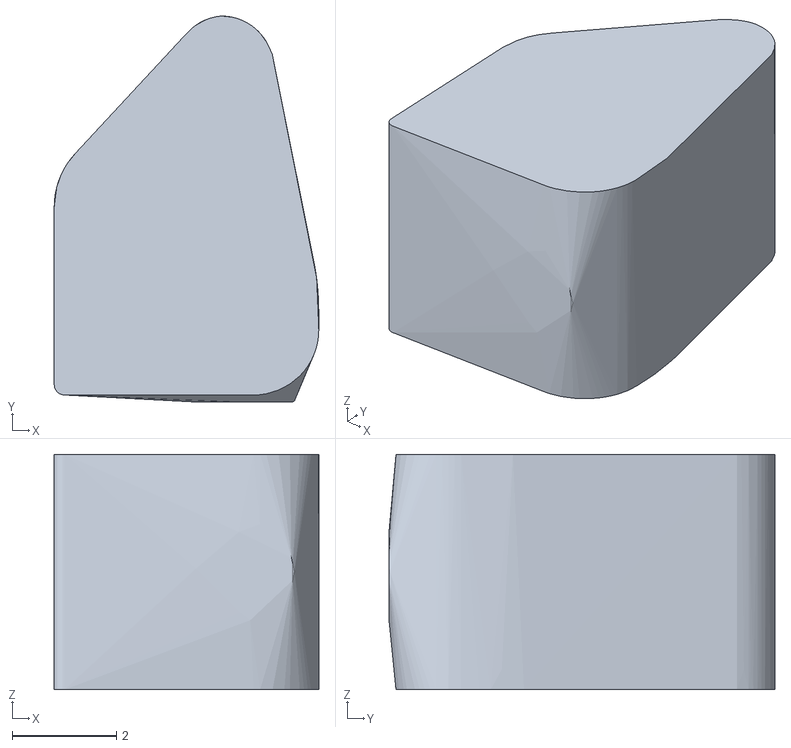
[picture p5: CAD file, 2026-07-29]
meshes/K2/Hip_roll_right_collision.stl
5.08 x 7.41 x 4.52

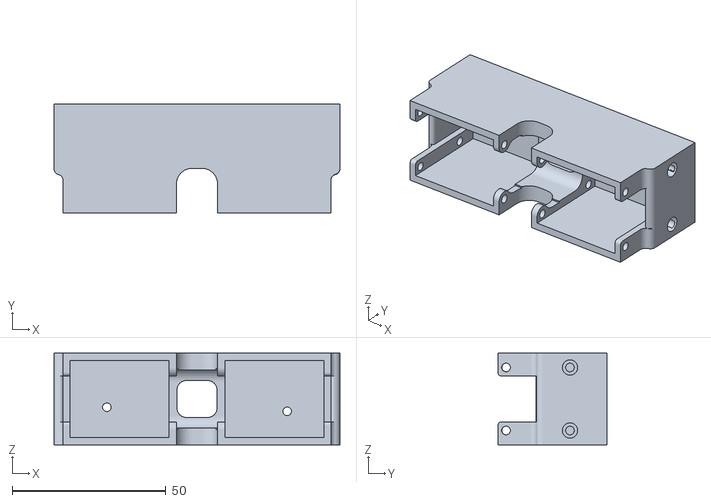
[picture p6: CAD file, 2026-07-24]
stl/Base_link.obj
93.0 x 35.6 x 29.9

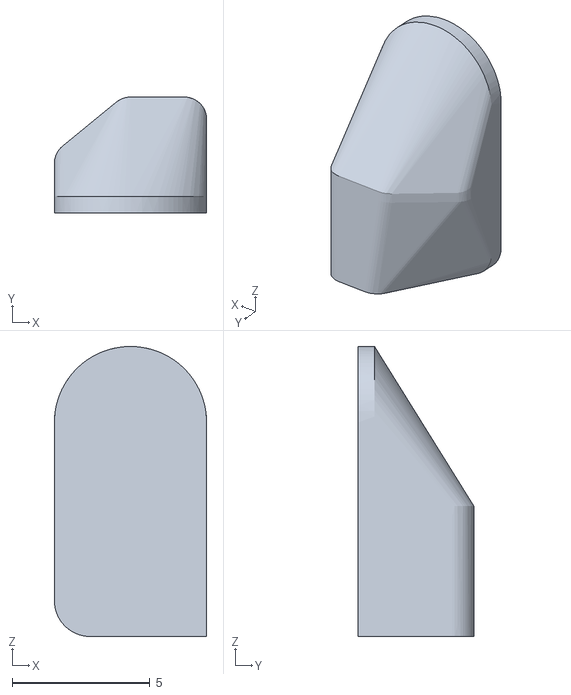
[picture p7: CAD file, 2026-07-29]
meshes/K2/Feet_right_collision.stl
5.52 x 4.20 x 10.5

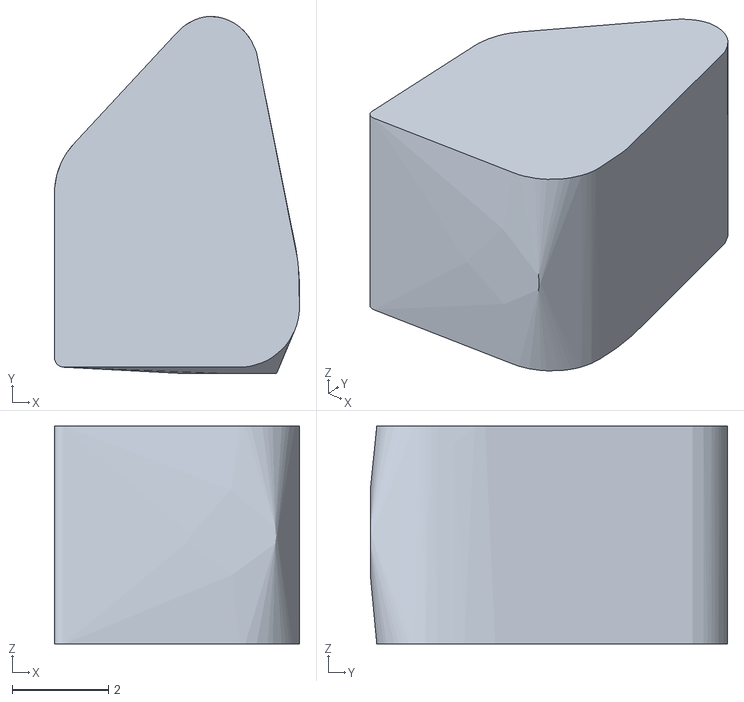
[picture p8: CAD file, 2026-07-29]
meshes/K2/Hip_roll_left_collision.stl
5.08 x 7.41 x 4.52

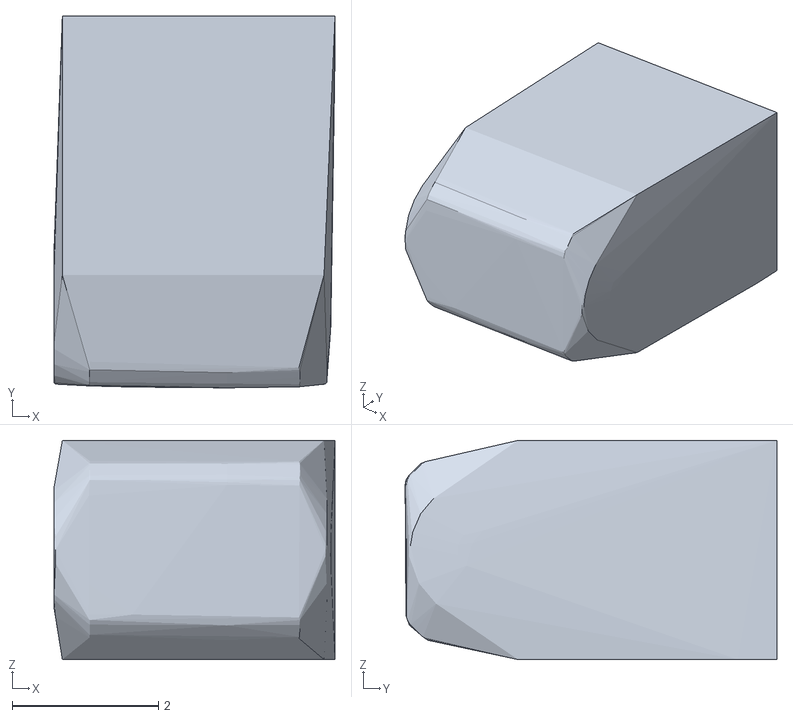
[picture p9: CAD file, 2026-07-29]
meshes/K2/Hip_yaw_left_collision.stl
3.84 x 5.08 x 2.99

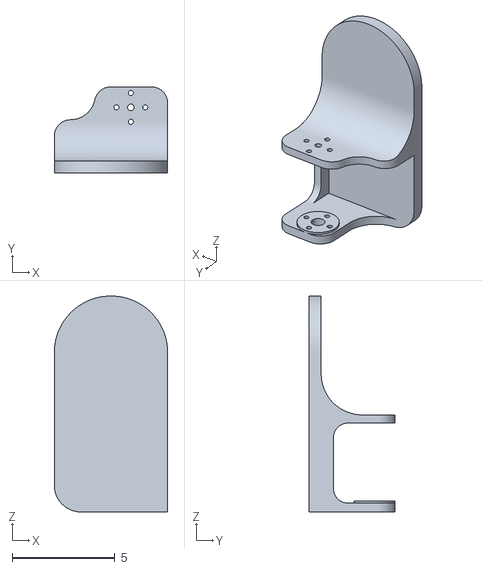
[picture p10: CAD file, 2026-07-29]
meshes/K2/Feet_right.obj
5.52 x 4.20 x 10.5

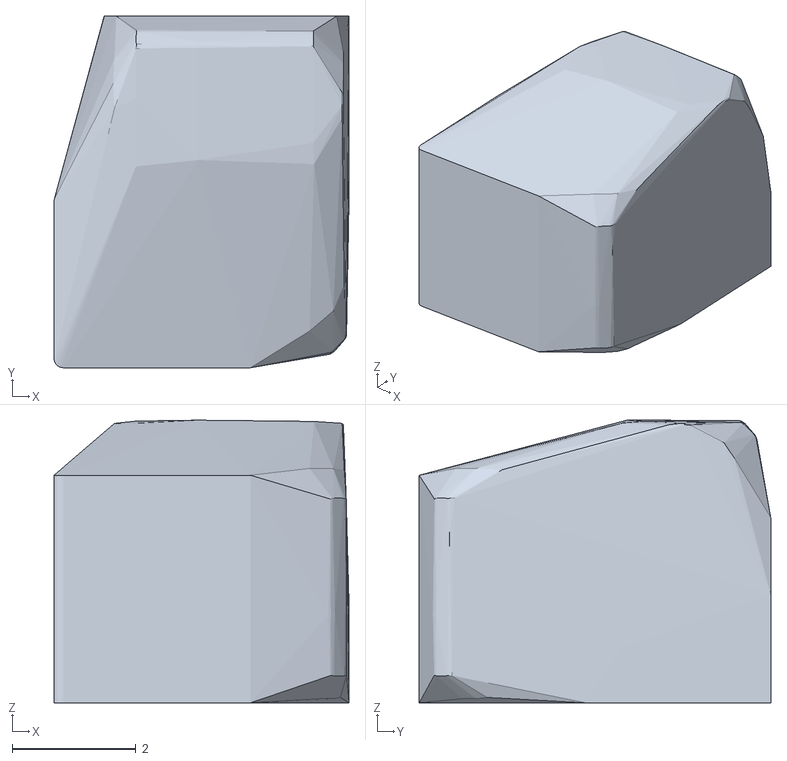
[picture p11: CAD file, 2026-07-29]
meshes/K2/Ankle_right_collision.stl
4.77 x 5.69 x 4.57

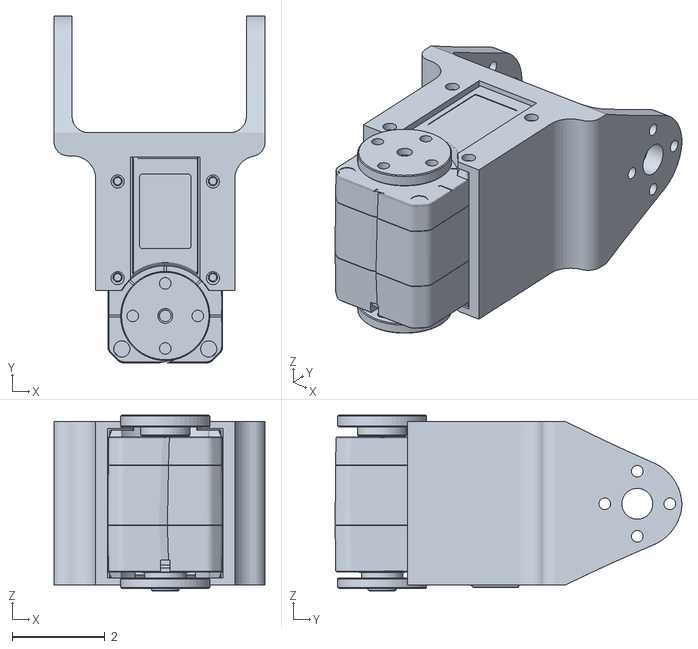
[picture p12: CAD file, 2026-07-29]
meshes/K2/Hip_pitch_right.obj
4.54 x 7.46 x 3.78

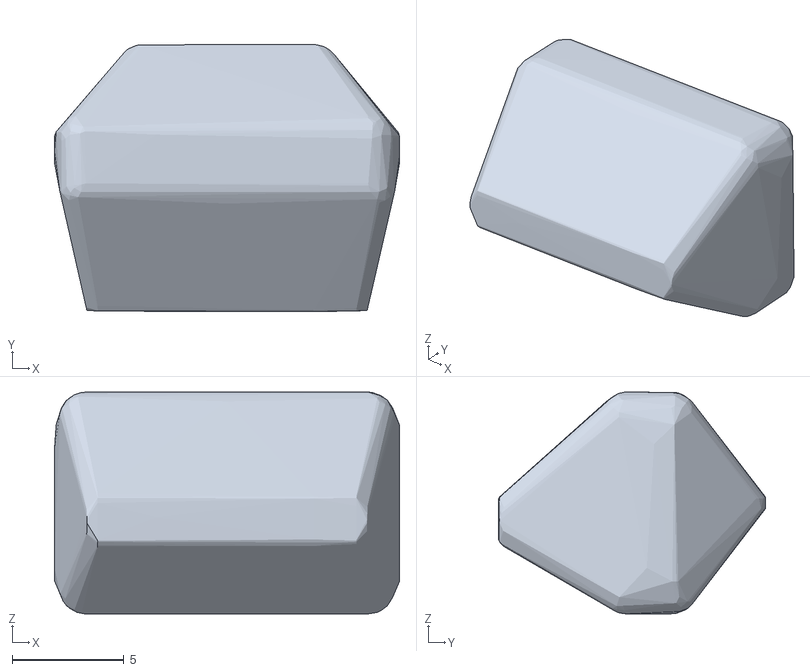
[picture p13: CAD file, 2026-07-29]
meshes/K2/base_link_collision.stl
15.4 x 11.9 x 9.90

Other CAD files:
meshes/K2/Hip_pitch_right_collision.stl
meshes/K2/Feet_left_collision.stl
meshes/K2/Ankle_left_collision.stl
meshes/K2/Feet_left.obj
meshes/K2/Hip_pitch_left.obj
meshes/K2/Hip_yaw_right_collision.stl
meshes/K2/Hip_roll_left.obj
meshes/K2/Hip_roll_right.obj
meshes/K2/Hip_yaw_left.obj
meshes/K2/Hip_yaw_right.obj
meshes/K2/Knee_left.obj
meshes/K2/Knee_left_collision.stl
meshes/K2/Knee_right.obj
meshes/K2/Knee_right_collision.stl

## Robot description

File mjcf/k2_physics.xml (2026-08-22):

<mujoco model="k2">
  <compiler angle="radian" meshdir="../meshes/K2" autolimits="true" />
  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
  <worldbody>
    <body name="k2_root" pos="0 0 0.314224" quat="1 0 0 0">
      <freejoint name="floating_base" />
      <body name="base_link" pos="-0.027327 0.000624 0" quat="0.5 0.5 0.5 0.5">
        <inertial pos="-0.001432 0.047148 0.002869" quat="-0.135872 0.690459 -0.149128 0.69467" mass="0.253045987" diaginertia="0.000586621415 0.000560769455 0.000208520753" />
        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
        <body name="hip_pitch_right" pos="0.062625 0.002806 0">
          <inertial pos="-0.003489 -0.006893 4.3e-05" quat="0.59469 0.384355 -0.591229 0.386088" mass="0.0811267606" diaginertia="2.58849754e-05 2.50053962e-05 3.79860037e-06" />
          <joint name="base_link_hip_pitch_right_joint" pos="0 0 0" axis="1 0 0" range="-1.0472 1.0472" actuatorfrcrange="-2.94 2.94" armature="0.01" />
          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
          <body name="hip_roll_right" pos="-0.017459 -0.054923 0.019072">
            <inertial pos="-0.002929 -0.012425 -0.00554" quat="0.54776 0.820599 -0.160987 -0.0256802" mass="0.0923129136" diaginertia="5.37733582e-05 5.2696881e-05 9.91466757e-06" />
            <joint name="hip_pitch_hip_roll_right_joint" pos="0 0 0" axis="0 0 1" range="-0.785398 0.785398" actuatorfrcrange="-2.94 2.94" armature="0.01" />
            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
            <body name="hip_yaw_right" pos="0.004021 -0.064534 -0.018738">
              <inertial pos="-0.001476 -0.003453 -7.3e-05" quat="0.570561 0.405631 -0.586006 0.408069" mass="0.0761310029" diaginertia="9.69609231e-06 9.24617003e-06 1.97225997e-06" />
              <joint name="hip_roll_hip_yaw_right_joint" pos="0 0 0" axis="0 -1 0" range="-1.5708 1.5708" actuatorfrcrange="-2.94 2.94" armature="0.01" />
              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
              <body name="Knee_right" pos="-0.0291 -0.040651 -0.0005">
                <inertial pos="0.005825 -0.014694 0.00122" quat="0.419175 0.540063 -0.425113 0.593214" mass="0.0944849822" diaginertia="8.33048023e-05 7.62425386e-05 1.01457431e-05" />
                <joint name="hip_yaw_knee_right_joint" pos="0 0 0" axis="-1 0 0" range="-1.5708 0.261799" actuatorfrcrange="-2.94 2.94" armature="0.01" />
                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
                <body name="ankle_right" pos="0.0375 -0.094922 0">
                  <inertial pos="-0.005655 -0.003784 -0.004105" quat="-0.117443 0.433775 0.273912 0.850305" mass="0.0890548108" diaginertia="2.5040801e-05 2.36713117e-05 7.79804107e-06" />
                  <joint name="knee_ankle_pitch_right_joint" pos="0 0 0" axis="-1 0 0" range="-0.436332 1.22173" actuatorfrcrange="-2.94 2.94" armature="0.01" />
                  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
                  <body name="Feet_right" pos="-0.00943 -0.028 0.0023">
                    <inertial pos="-0.001417 -0.004521 0.000282" quat="0.936909 0.268629 -0.0799101 -0.208935" mass="0.0803665366" diaginertia="2.10949126e-05 1.56563788e-05 1.15413949e-05" />
                    <joint name="ankle_roll_foot_right_joint" pos="0 0 0" axis="0 0 1" range="-0.349066 0.698132" actuatorfrcrange="-2.94 2.94" armature="0.01" />
                    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
                  </body>
                </body>
              </body>
            </body>
          </body>
        </body>
        <body name="hip_pitch_left" pos="-0.062625 0.002806 0" quat="0 1.73205e-07 -1 -1.73205e-07">
          <inertial pos="-0.003489 -0.006893 -4.3e-05" quat="0.591229 0.386089 -0.59469 0.384354" mass="0.0811267606" diaginertia="2.58849754e-05 2.50053962e-05 3.79860037e-06" />
          <joint name="base_link_hip_pitch_left_joint" pos="0 0 0" axis="-1 0 0" range="-1.0472 1.0472" actuatorfrcrange="-2.94 2.94" armature="0.01" />
          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
          <body name="hip_roll_left" pos="-0.017459 -0.054923 -0.019072">
            <inertial pos="-0.002929 -0.012425 0.00554" quat="0.820599 0.54776 -0.0256804 -0.160987" mass="0.0923129136" diaginertia="5.37733582e-05 5.2696881e-05 9.91466757e-06" />
            <joint name="hip_pitch_hip_roll_left_joint" pos="0 0 0" axis="0 0 1" range="-0.785398 0.785398" actuatorfrcrange="-2.94 2.94" armature="0.01" />
            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
            <body name="hip_yaw_left" pos="0.004021 -0.064534 0.018738">
              <inertial pos="-0.001476 -0.003453 7.3e-05" quat="0.586006 0.408069 -0.570561 0.405631" mass="0.0761310029" diaginertia="9.69609231e-06 9.24617003e-06 1.97225997e-06" />
              <joint name="hip_roll_hip_yaw_left_joint" pos="0 0 0" axis="0 1 0" range="-1.5708 1.5708" actuatorfrcrange="-2.94 2.94" armature="0.01" />
              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
              <body name="Knee_left" pos="-0.0291 -0.040651 0.0005">
                <inertial pos="0.005825 -0.014694 -0.00122" quat="0.425113 0.593214 -0.419175 0.540063" mass="0.0944849822" diaginertia="8.33048023e-05 7.62425386e-05 1.01457431e-05" />
                <joint name="hip_yaw_knee_left_joint" pos="0 0 0" axis="1 0 0" range="-1.5708 0.261799" actuatorfrcrange="-2.94 2.94" armature="0.01" />
                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
                <body name="ankle_left" pos="0.0375 -0.094922 0">
                  <inertial pos="-0.005655 -0.003784 0.004105" quat="-0.273912 0.850305 0.117443 0.433775" mass="0.0890548108" diaginertia="2.5040801e-05 2.36713117e-05 7.79804107e-06" />
                  <joint name="knee_ankle_pitch_left_joint" pos="0 0 0" axis="1 0 0" range="-0.436332 1.22173" actuatorfrcrange="-2.94 2.94" armature="0.01" />
                  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
                  <body name="Feet_left" pos="-0.00943 -0.028 -0.0023">
                    <inertial pos="-0.001417 -0.004521 -0.000282" quat="0.936909 -0.268629 0.0799101 -0.208935" mass="0.0803665366" diaginertia="2.10949126e-05 1.56563788e-05 1.15413949e-05" />
                    <joint name="ankle_roll_foot_left_joint" pos="0 0 0" axis="0 0 1" range="-0.349066 0.698132" actuatorfrcrange="-2.94 2.94" armature="0.01" />
                    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
                  </body>
                </body>
              </body>
            </body>
          </body>
        </body>
        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
      </body>
    </body>
    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
    <light pos="0 0 3" dir="0 0 -1" directional="true" />
  </worldbody>
  <option timestep="0.002" integrator="implicitfast" />
  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
  <sensor>
    <gyro name="imu_ang_vel" site="imu" />
    <velocimeter name="imu_lin_vel" site="imu" />
    <accelerometer name="imu_lin_acc" site="imu" />
    <framequat name="imu_quat" objtype="site" objname="imu" />
    <subtreeangmom name="root_angmom" body="base_link" />
    <framepos name="right_foot_pos" objtype="site" objname="right_foot" />
    <framelinvel name="right_foot_vel" objtype="site" objname="right_foot" />
    <framepos name="left_foot_pos" objtype="site" objname="left_foot" />
    <framelinvel name="left_foot_vel" objtype="site" objname="left_foot" />
  </sensor>
</mujoco>

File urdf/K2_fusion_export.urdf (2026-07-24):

<?xml version="1.0"?>
<robot name="Robot_v4">

  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

  <link name="base_link">
    <inertial>
      <origin xyz="0.027914 0.011270 0.003243" rpy="0 0 0"/>
      <mass value="1.196448"/>
      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
    </inertial>
    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
  </link>

  <link name="Hip_pitch_right">
    <inertial>
      <origin xyz="-0.007803 -0.027041 0.000209" rpy="0 0 0"/>
      <mass value="0.470867"/>
      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
    </inertial>
    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
  </link>

  <link name="Hip_pitch_left">
    <inertial>
      <origin xyz="-0.007803 -0.027041 -0.000209" rpy="0 0 0"/>
      <mass value="0.470867"/>
      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
    </inertial>
    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
  </link>

  <link name="Hip_roll_right">
    <inertial>
      <origin xyz="0.042246 0.009959 0.018837" rpy="0 0 0"/>
      <mass value="0.567771"/>
      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
    </inertial>
    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
  </link>

  <link name="Hip_roll_left">
    <inertial>
      <origin xyz="0.042246 0.009959 -0.018837" rpy="0 0 0"/>
      <mass value="0.567771"/>
      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
    </inertial>
    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
  </link>

  <link name="Hip_yaw_right">
    <inertial>
      <origin xyz="0.010788 -0.045739 0.000504" rpy="0 0 0"/>
      <mass value="0.400297"/>
      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
    </inertial>
    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
  </link>

  <link name="Hip_yaw_left">
    <inertial>
      <origin xyz="0.010788 -0.045739 -0.000504" rpy="0 0 0"/>
      <mass value="0.400297"/>
      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
    </inertial>
    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
  </link>

  <link name="Knee_right">
    <inertial>
      <origin xyz="0.018769 -0.047347 0.003932" rpy="0 0 0"/>
      <mass value="0.212616"/>
      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
    </inertial>
    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
  </link>

  <link name="Knee_left">
    <inertial>
      <origin xyz="0.018769 -0.047347 -0.003932" rpy="0 0 0"/>
      <mass value="0.212616"/>
      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
    </inertial>
    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
  </link>

  <link name="Ankle_right">
    <inertial>
      <origin xyz="-0.021076 0.015301 -0.014103" rpy="0 0 0"/>
      <mass value="0.650099"/>
      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
    </inertial>
    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
  </link>

  <link name="Ankle_left">
    <inertial>
      <origin xyz="-0.021076 0.015301 0.014103" rpy="0 0 0"/>
      <mass value="0.650100"/>
      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
    </inertial>
    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
  </link>

  <link name="Feet_right">
    <inertial>
      <origin xyz="-0.007940 -0.023198 0.001344" rpy="0 0 0"/>
      <mass value="0.398908"/>
      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
    </inertial>
    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
  </link>

  <link name="Feet_left">
    <inertial>
      <origin xyz="-0.007940 -0.023198 -0.001344" rpy="0 0 0"/>
      <mass value="0.398908"/>
      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
    </inertial>
    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
  </link>

  <joint name="base_link_hip_pitch_right_joint" type="revolute">
    <parent link="base_link"/>
    <child link="Hip_pitch_right"/>
    <origin xyz="0.079600 -0.022600 -0.000000" rpy="-0.000000 -0.000000 0.000000"/>
    <axis xyz="1.000000 -0.000000 0.000000"/>
    <limit lower="-1.047198" upper="1.047198" effort="100.0" velocity="1.00"/>
  </joint>

  <joint name="base_link_hip_pitch_left_joint" type="revolute">
    <parent link="base_link"/>
    <child link="Hip_pitch_left"/>
    <origin xyz="-0.023600 -0.022500 0.000000" rpy="-3.141593 0.000000 -3.141593"/>
    <axis xyz="-1.000000 0.000000 0.000000"/>
    <limit lower="-1.047198" upper="1.047198" effort="100.0" velocity="1.00"/>
  </joint>

  <joint name="hip_pitch_hip_roll_right_joint" type="revolute">
    <parent link="Hip_pitch_right"/>
    <child link="Hip_roll_right"/>
    <origin xyz="0.015944 -0.029434 0.019072" rpy="3.141593 0.000000 -1.570796"/>
    <axis xyz="-0.000000 0.000000 -1.000000"/>
    <limit lower="-0.383972" upper="1.570796" effort="100.0" velocity="1.00"/>
  </joint>

  <joint name="hip_pitch_hip_roll_left_joint" type="revolute">
    <parent link="Hip_pitch_left"/>
    <child link="Hip_roll_left"/>
    <origin xyz="0.015944 -0.029434 -0.019072" rpy="-3.141593 -0.000000 -1.570796"/>
    <axis xyz="0.000000 -0.000000 -1.000000"/>
    <limit lower="-0.383972" upper="1.570796" effort="100.0" velocity="1.00"/>
  </joint>

  <joint name="hip_roll_hip_yaw_right_joint" type="revolute">
    <parent link="Hip_roll_right"/>
    <child link="Hip_yaw_right"/>
    <origin xyz="0.064534 -0.004021 0.018738" rpy="-0.000000 0.000000 1.570796"/>
    <axis xyz="-0.000000 -1.000000 -0.000000"/>
    <limit lower="-1.570796" upper="1.570796" effort="100.0" velocity="1.00"/>
  </joint>

  <joint name="hip_roll_hip_yaw_left_joint" type="revolute">
    <parent link="Hip_roll_left"/>
    <child link="Hip_yaw_left"/>
    <origin xyz="0.064534 -0.004021 -0.018738" rpy="0.000000 -0.000000 1.570796"/>
    <axis xyz="0.000000 1.000000 -0.000000"/>
    <limit lower="-1.570796" upper="1.570796" effort="100.0" velocity="1.00"/>
  </joint>

  <joint name="hip_yaw_knee_right_joint" type="revolute">
    <parent link="Hip_yaw_right"/>
    <child link="Knee_right"/>
    <origin xyz="0.029100 -0.068651 0.000500" rpy="-3.141593 -0.000000 -3.141593"/>
    <axis xyz="-1.000000 -0.000000 -0.000000"/>
    <limit lower="-0.261799" upper="1.919862" effort="100.0" velocity="1.00"/>
  </joint>

  <joint name="hip_yaw_knee_left_joint" type="revolute">
    <parent link="Hip_yaw_left"/>
    <child link="Knee_left"/>
    <origin xyz="0.029100 -0.068651 -0.000500" rpy="3.141593 0.000000 -3.141593"/>
    <axis xyz="1.000000 0.000000 -0.000000"/>
    <limit lower="-1.919862" upper="0.261799" effort="100.0" velocity="1.00"/>
  </joint>
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

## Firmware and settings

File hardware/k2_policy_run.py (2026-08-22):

#!/usr/bin/env python3
"""Run a trained K2 RL policy (ONNX) over the Bus. Same code, sim or real.

    # digital twin (MuJoCo):
    python -m hardware.k2_policy_run --bus sim --viewer --mode march --policy <policy.onnx>
    # real robot (Pi):
    python -m hardware.k2_policy_run --bus /dev/ttyAMA0 --mode hold --policy <policy.onnx>

The policy is a hold/march or command-conditioned walking net from `k2_rl`.
Its 45-D (legacy march), 46-D (initial forward), 48-D (heading-aware forward /
bidirectional), or 49-D (turning) observation is rebuilt byte-for-byte the way
the training environment built it:

    obs = [ base_ang_vel(3)      # gyro, IMU/site frame
            projected_gravity(3) # gravity dir, k2_root frame
            joint_pos_rel(12)    # q - default_pose, SIM_ORDER
            joint_vel_rel(12)    # qdot, SIM_ORDER
            last_action(12)      # previous RAW policy output
            heading(0 or 2)      # optional [sin, cos] of the HEADING ERROR
            gait(3..6) ]         # [march, m*sin, m*cos, vx, wz, dh]

On a 5-D (turning) policy the heading channel is the error against a reference
heading obtained by integrating the yaw rate this runner itself commanded --
exactly what `k2_rl.mdp.GaitCommand` integrates during training. With no yaw
command that reference stays at zero and the channel is the plain relative
heading a 48-D policy expects, so the older policies run unchanged.

Joint order, default pose and action scale are read from the ONNX metadata, so
this stays correct if the policy is retrained. Actions are position targets:
    q_target = default_pose + action_scale * action
clamped to joint limits (and counts [40,4055] in the bus). The IMU obs comes
from SimAttitude (sim) or ImuAttitude (real LSM6DS3), which share one interface.

Safety (real robot): torque always released on exit incl. Ctrl-C; optional
--slew caps per-tick joint motion; the robot is eased into the default crouch
before the policy takes over.
"""

from __future__ import annotations

import argparse
import math
import signal
import sys
import time

import numpy as np
import onnxruntime as ort

from . import k2_conventions as C
from . import k2_bus
from .k2_attitude import SimAttitude, ImuAttitude
from .k2_stabilizer import UnsafeTiltError

RATE_HZ = 50.0
APPROACH_S = 5.0
LEGACY_GAIT_FREQ_HZ = 0.75  # checkpoint 2000 predates gait metadata


def _read_metadata(sess: ort.InferenceSession):
  """Pull the deployment contract out of the ONNX."""
  md = sess.get_modelmeta().custom_metadata_map
  mjcf_names = md["joint_names"].split(",")
  default_pos = np.array([float(x) for x in md["default_joint_pos"].split(",")],
                         dtype=np.float32)
  action_scale = float(md["action_scale"])
  gait_freq_hz = float(md.get("gait_frequency_hz", LEGACY_GAIT_FREQ_HZ))
  gait_transition_time_s = float(md.get("gait_transition_time_s", "0.0"))
  gait_velocity_ramp_rate_mps2 = float(
    md.get("gait_velocity_ramp_rate_mps2", "0.08")
  )
  gait_yaw_rate_ramp_rate_rps2 = float(
    md.get("gait_yaw_rate_ramp_rate_rps2", "0.30")
  )
  gait_height_ramp_rate_mps = float(md.get("gait_height_ramp_rate_mps", "0.03"))
  checkpoint_iteration = md.get("checkpoint_iteration", "unknown")
  neutral_base_shift_m = float(md.get("neutral_base_shift_m", "nan"))
  obs_dim = int(sess.get_inputs()[0].shape[-1])
  if obs_dim == 45:
    inferred_heading_dim, inferred_gait_dim = 0, 3
  elif obs_dim == 46:
    inferred_heading_dim, inferred_gait_dim = 0, 4
  elif obs_dim == 48:
    inferred_heading_dim, inferred_gait_dim = 2, 4
  elif obs_dim == 49:
    inferred_heading_dim, inferred_gait_dim = 2, 5
  elif obs_dim == 50:
    inferred_heading_dim, inferred_gait_dim = 2, 6
  else:
    raise SystemExit(f"unsupported policy observation size: {obs_dim}")
  gait_command_dim = int(md.get("gait_command_dim", inferred_gait_dim))
  heading_observation_dim = int(
    md.get("heading_observation_dim", inferred_heading_dim)
  )
  # Map the policy's MJCF joint order to our SIM_ORDER short names.
  mjcf_to_short = {v: k for k, v in C.JOINT_TO_MJCF.items()}
  policy_short = [mjcf_to_short[n] for n in mjcf_names]
  if tuple(policy_short) != tuple(C.SIM_ORDER):
    raise SystemExit(
      "policy joint order != SIM_ORDER; permutation not implemented.\n"
      f"  policy: {policy_short}\n  sim   : {list(C.SIM_ORDER)}")
  if default_pos.shape != (len(C.SIM_ORDER),) or not np.all(np.isfinite(default_pos)):
    raise SystemExit("policy metadata has an invalid default_joint_pos")
  outside = [
    name for i, name in enumerate(C.SIM_ORDER)
    if not C.LIMITS[name][0] <= float(default_pos[i]) <= C.LIMITS[name][1]
  ]
  if outside:
    raise SystemExit(f"policy default pose exceeds joint limits: {outside}")
  if not 0.0 < action_scale <= 0.5:
    raise SystemExit(f"unsafe policy action scale: {action_scale:g}")
  if gait_command_dim not in (3, 4, 5, 6) or gait_command_dim != inferred_gait_dim:
    raise SystemExit(
      f"unsupported/inconsistent gait interface: metadata={gait_command_dim}, "
      f"observation implies {inferred_gait_dim}"
    )
  if (heading_observation_dim not in (0, 2)
      or heading_observation_dim != inferred_heading_dim):
    raise SystemExit(
      f"unsupported/inconsistent heading interface: "
      f"metadata={heading_observation_dim}, observation implies "
      f"{inferred_heading_dim}"
    )
  return (default_pos, action_scale, gait_freq_hz,
          checkpoint_iteration, neutral_base_shift_m, gait_command_dim,
          heading_observation_dim, gait_transition_time_s,
          gait_velocity_ramp_rate_mps2, gait_yaw_rate_ramp_rate_rps2,
          gait_height_ramp_rate_mps)


SWAP_LEGS = np.array([6, 7, 8, 9, 10, 11, 0, 1, 2, 3, 4, 5])
MAX_JOINT_TRIM_DEG = 10.0


def parse_joint_trim(spec: str | None) -> np.ndarray:
  """Parse "hip_yaw_R=+2.5,hip_yaw_L=-2.5" into a SIM_ORDER vector in radians.

  A mechanical asymmetry -- a foot mounted at a slight yaw, one leg built a
  fraction long -- forces the policy to hold a permanent differential just to
  stand square, and it has to spend control authority doing so every tick. The
  trim moves that differential into the wiring: the policy is shown a SYMMETRIC
  robot, and the offset is added back on the way out to the servos.

      observation : joint_pos_rel = (q - trim) - default_pose
      command     : q_target      = default_pose + scale * action + trim

  which is the same shape as the `encoder_bias` randomization the policy trained
  against, so it is in-distribution by construction. Reverts by omission.
  """
  trim = np.zeros(len(C.SIM_ORDER), dtype=np.float32)
  if not spec:
    return trim
  index = {name: i for i, name in enumerate(C.SIM_ORDER)}
  for item in spec.split(","):
    item = item.strip()
    if not item:
      continue
    if "=" not in item:
      raise SystemExit(f"--joint-trim needs NAME=DEGREES, got '{item}'")
    name, _, value = item.partition("=")
    name = name.strip()
    if name not in index:
      raise SystemExit(
        f"unknown joint '{name}' in --joint-trim; expected one of "
        f"{', '.join(C.SIM_ORDER)}")
    try:
      degrees = float(value)
    except ValueError:
      raise SystemExit(f"--joint-trim value for {name} is not a number: {value}")
    if abs(degrees) > MAX_JOINT_TRIM_DEG:
      raise SystemExit(
        f"--joint-trim {name}={degrees:g} exceeds the +/-{MAX_JOINT_TRIM_DEG:g} "
        "degree guard; a trim that large is a calibration problem, not a trim")
    trim[index[name]] = math.radians(degrees)
  return trim


def run(bus, sess, default_pos, action_scale, mode, duration, slew_rad_s,
        march_after, gait_freq_hz, approach_s=APPROACH_S,
        fall_angle_deg=12.0, log=None, swap_legs=False, forward_speed=0.03,
        heading_observation_dim=0, balance_trim_right_deg=0.0,
        gait_transition_time_s=0.0, command_source=None,
        gait_velocity_ramp_rate_mps2=0.08, yaw_rate=0.0,
        gait_yaw_rate_ramp_rate_rps2=0.30, joint_trim=None,
        height_offset=0.0, gait_height_ramp_rate_mps=0.03):
  dt = 1.0 / RATE_HZ
  iname = sess.get_inputs()[0].name
  # Route the policy's right-leg block to the other physical leg. Equivalent to
  # permuting JOINT_TO_ID and calibration.json together (each servo keeps its
  # own home_raw/sign, and every POS_DESC is mirror-symmetric so the signs stay
  # valid) -- but as a flag, so it reverts by omission. Diagnostic only.
  perm = SWAP_LEGS if swap_legs else np.arange(len(C.SIM_ORDER))
  # Physical, per-servo quantity: applied in SIM_ORDER, never permuted. NOTE the
  # name: `trim` below is the scalar balance-trim ANGLE, a different thing.
  joint_trim_rad = (np.zeros(len(C.SIM_ORDER), np.float32) if joint_trim is None
                    else np.asarray(joint_trim, np.float32))
  if np.any(joint_trim_rad):
    shown = ", ".join(f"{C.SIM_ORDER[i]}={math.degrees(v):+.2f}"
                      for i, v in enumerate(joint_trim_rad) if v)
    print(f"  joint trim (deg): {shown}")

  calib = (C.default_calibration() if isinstance(bus, k2_bus.SimBus)
           else _hw_calibration())
  att = SimAttitude(bus) if isinstance(bus, k2_bus.SimBus) else ImuAttitude()
  fall_angle = math.radians(fall_angle_deg)
  # A positive user trim must move the learned support response toward -Y
  # (robot-right). The policy's response sign was verified in the twin with a
  # +10 mm robot-left base CoM perturbation, hence the negative virtual roll.
  trim = -math.radians(balance_trim_right_deg)
  trim_cos, trim_sin = math.cos(trim), math.sin(trim)

  def attitude():
    gyro, gravity = (att.attitude() if isinstance(bus, k2_bus.SimBus)
                     else att.attitude(dt))
    gravity = np.asarray(gravity, np.float32)
    gravity /= max(float(np.linalg.norm(gravity)), 1e-6)
    tilt = math.acos(float(np.clip(-gravity[2], -1.0, 1.0)))
    if tilt > fall_angle:
      raise UnsafeTiltError(
        f"torso tilt {math.degrees(tilt):.1f} deg exceeds "
        f"{fall_angle_deg:.1f} deg")
    return gyro, gravity, tilt

  rows = []
  tracking_errors = []
  telemetry_samples = []
  sim_diag = {
    "swing_spread": [],
    "apex_clearance": [],
    "inner_gap": [],
    "foot_contacts": 0,
  }

  def sample_sim_feet(sinp, marching):
    if not isinstance(bus, k2_bus.SimBus):
      return
    model, data = bus.model, bus.data
    points = {}
    for side in ("left", "right"):
      points[side] = np.array([
        data.site_xpos[model.site(f"{side}_foot_{part}").id].copy()
        for part in ("heel", "toe", "inner", "outer")
      ])
    inner_l = data.site_xpos[model.site("left_foot_inner").id]
    inner_r = data.site_xpos[model.site("right_foot_inner").id]
    sim_diag["inner_gap"].append(abs(float(inner_l[1] - inner_r[1])))
    if marching and abs(sinp) > 0.18:
      # SceneEntityCfg resolves the MJCF site order (right, then left).
      side = "right" if sinp > 0 else "left"
      z = points[side][:, 2]
      sim_diag["swing_spread"].append(float(np.max(z) - np.min(z)))
      if abs(sinp) > 0.90:
        sim_diag["apex_clearance"].append(float(np.min(z)))

    left_gid = model.geom("left_foot_collision").id
    right_gid = model.geom("right_foot_collision").id
    for contact in data.contact:
      if {int(contact.geom1), int(contact.geom2)} == {left_gid, right_gid}:
        sim_diag["foot_contacts"] += 1

  def print_sim_diagnostics():
    if not isinstance(bus, k2_bus.SimBus) or not sim_diag["inner_gap"]:
      return
    spread = np.asarray(sim_diag["swing_spread"])
    apex = np.asarray(sim_diag["apex_clearance"])
    gap = np.asarray(sim_diag["inner_gap"])
    print("  sole diagnostics:")
    if len(spread):
      print(f"    max swing sole height spread: {spread.max()*1000:.1f} mm")
    if len(apex):
      print(f"    minimum apex clearance (all sole points): {apex.min()*1000:.1f} mm")
    print(f"    minimum inner-edge gap: {gap.min()*1000:.1f} mm")
    print(f"    foot-to-foot collision contacts: {sim_diag['foot_contacts']}")

  def write_log():
    if log is None or not rows:
      return
    header = ["t", "t_nominal", "loop_dt", "march", "phase",
              "forward_command", "yaw_command", "height_command",
              "heading_reference",
              "base_x", "base_y", "base_z", "base_heading",
              "heading_sin", "heading_cos", "tilt",
              "gyro_x", "gyro_y", "gyro_z",
              "gravity_x", "gravity_y", "gravity_z",
              "policy_gravity_x", "policy_gravity_y", "policy_gravity_z"]
    header += [f"action_{j}" for j in C.SIM_ORDER]
    header += [f"cmd_{j}" for j in C.SIM_ORDER]
    header += [f"q_{j}" for j in C.SIM_ORDER]
    header += [f"qd_{j}" for j in C.SIM_ORDER]
    header += [f"error_{j}" for j in C.SIM_ORDER]
    for field in ("load", "current_raw", "voltage", "temperature", "status",
                  "telemetry_outlier"):
      header += [f"{field}_{j}" for j in C.SIM_ORDER]
    np.savetxt(log, np.asarray(rows), delimiter=",",
               header=",".join(header), comments="")
    print(f"wrote {log}")

  try:
    # 1) Ease from the current pose into the default crouch. The policy is not
    # active yet, but the IMU safety cutoff is.
    pos, _ = bus.read_pos_speed()
    q_now = C.q_vector(pos, calib)
    n_appr = int(approach_s / dt)
    for i in range(n_appr):
      attitude()
      a = 0.5 * (1 - math.cos(math.pi * i / n_appr))
      cmd = q_now + (default_pos - q_now) * a
      bus.write_goals(C.goal_counts(cmd, calib))
      bus.tick(dt)

    # 2) Policy loop.
    last_action = np.zeros(12, dtype=np.float32)
    phase = 0.0
    gait_activation = 0.0
    interactive_forward_speed = 0.0
    interactive_yaw_rate = 0.0
    interactive_height = 0.0
    # Reference heading the commanded yaw rate asks the robot to face. Training
    # integrates exactly this from the same emitted command, so a 5-D policy
    # sees the same near-zero heading error here that it saw in simulation.
    heading_reference = 0.0
    cmd = default_pos.copy()
    n_steps = int(duration * RATE_HZ)
    t0 = time.perf_counter()
    previous_tick_time = t0
    ran_steps = 0
    for k in range(n_steps):
      active_mode = mode
      active_forward_speed = forward_speed
      active_yaw_rate = yaw_rate
      active_height = height_offset
      if command_source is not None:
        source = command_source()
        if len(source) == 5:
          (active_mode, active_forward_speed, active_yaw_rate,
           active_height, stop_requested) = source
        else:
          (active_mode, active_forward_speed, active_yaw_rate,
           stop_requested) = source
          active_height = height_offset
        if stop_requested:
          print("  keyboard quit requested")
          break
        if active_mode not in ("hold", "march", "walk"):
          raise UnsafeTiltError(f"invalid interactive mode: {active_mode}")
        # Training rate-limits signed command resamples. Do the same here so
        # W<->S and A<->D never ask the policy or the robot for an
        # instantaneous reversal.
        speed_target = active_forward_speed if active_mode == "walk" else 0.0
        speed_step = gait_velocity_ramp_rate_mps2 * dt
        interactive_forward_speed += float(np.clip(
          speed_target - interactive_forward_speed, -speed_step, speed_step
        ))
        yaw_target = (active_yaw_rate
                      if active_mode in ("march", "walk") else 0.0)
        yaw_step = gait_yaw_rate_ramp_rate_rps2 * dt
        interactive_yaw_rate += float(np.clip(
          yaw_target - interactive_yaw_rate, -yaw_step, yaw_step
        ))
        # Crouch belongs to standing: the target collapses to zero the moment a
        # gait is requested, matching the (1 - march) gate used in training.
        height_target = active_height if active_mode == "hold" else 0.0
        height_step = gait_height_ramp_rate_mps * dt
        interactive_height += float(np.clip(
          height_target - interactive_height, -height_step, height_step
        ))
      ran_steps += 1
      tick_time = time.perf_counter()
      loop_dt = tick_time - previous_tick_time
      previous_tick_time = tick_time
      pos, spd = bus.read_pos_speed()
      q = C.q_vector(pos, calib).astype(np.float32)
      qd = C.qd_vector(spd, calib).astype(np.float32)
      telemetry = bus.latest_telemetry()
      if telemetry is None:
        telemetry_arrays = [np.full(12, np.nan, np.float32) for _ in range(6)]
      else:
        telemetry_arrays = [
          np.array([telemetry[C.JOINT_TO_ID[j]][field] for j in C.SIM_ORDER],
                   np.float32)
          for field in ("load_signed", "current_raw", "voltage_v",
                        "temperature_c", "error_status", "temperature_outlier")
        ]
        telemetry_samples.append(np.stack(telemetry_arrays))
      gyro, proj_grav, tilt = attitude()
      # Positive trim shifts the policy's closed-loop support response toward
      # the robot's right, countering a repeatable robot-left lean.
      # Safety and the raw gravity columns always retain the true IMU estimate.
      policy_grav = proj_grav.copy()
      policy_grav[1] = trim_cos * proj_grav[1] - trim_sin * proj_grav[2]
      policy_grav[2] = trim_sin * proj_grav[1] + trim_cos * proj_grav[2]
      # Gait command: march from the start, or after `march_after` seconds.
      marching = active_mode in ("march", "walk") and k * dt >= march_after
      gait_target = 1.0 if marching else 0.0
      if gait_transition_time_s > 0.0:
        activation_step = dt / gait_transition_time_s
        gait_activation += float(np.clip(
          gait_target - gait_activation, -activation_step, activation_step
        ))
      else:
        gait_activation = gait_target
      m = gait_activation
      # Match training: finish the smooth activation in double support, then
      # begin the first swing from phase zero.
      if marching and m >= 1.0 - 1e-6:
        phase = (phase + 2 * math.pi * gait_freq_hz * dt) % (2 * math.pi)
      elif m <= 0.0:
        phase = 0.0
      gait_values = [m, m * math.sin(phase), m * math.cos(phase)]
      if command_source is None:
        forward_command = (m * active_forward_speed
                           if active_mode == "walk" else 0.0)
        yaw_command = (m * active_yaw_rate
                       if active_mode in ("march", "walk") else 0.0)
      else:
        forward_command = m * interactive_forward_speed
        yaw_command = m * interactive_yaw_rate
      expected_obs = sess.get_inputs()[0].shape[-1]
      if expected_obs in (46, 48, 49, 50):
        gait_values.append(forward_command)
      if expected_obs in (49, 50):
        gait_values.append(yaw_command)
      else:
        # A policy without a yaw channel cannot be steered; keep the reference
        # pinned so its heading observation stays the plain relative heading.
        yaw_command = 0.0
      if expected_obs == 50:
        if command_source is None:
          height_command = ((1.0 - m) * active_height
                            if active_mode == "hold" else 0.0)
        else:
          height_command = (1.0 - m) * interactive_height
        gait_values.append(height_command)
      else:
        height_command = 0.0
      gait = np.asarray(gait_values, np.float32)

      # Advance the reference heading with the command just emitted, then read
      # the heading error against it -- the same order as training, where
      # GaitCommand integrates the reference at the end of its command update
      # and the observation manager runs immediately afterwards.
      heading_reference += yaw_command * dt
      heading_reference = (heading_reference + math.pi) % (2 * math.pi) - math.pi
      if heading_observation_dim == 2:
        heading_error = att.relative_heading() - heading_reference
        heading_obs = np.array(
          [math.sin(heading_error), math.cos(heading_error)], np.float32)
      else:
        heading_obs = np.empty(0, np.float32)

      obs_parts = [
        gyro.astype(np.float32),          # base_ang_vel
        policy_grav.astype(np.float32),   # projected_gravity with balance trim
        (q - joint_trim_rad - default_pos)[perm],  # joint_pos_rel, trimmed
        qd[perm],                         # joint_vel_rel
        last_action,                      # actions
        heading_obs,                      # optional [sin(yaw), cos(yaw)]
        gait,                             # gait command
      ]
      obs = np.concatenate(obs_parts).astype(np.float32)[None]
      if obs.shape[1] != expected_obs:
        raise UnsafeTiltError(
          f"policy expects {expected_obs} observations, built {obs.shape[1]}")

      action = sess.run(None, {iname: obs})[0][0].astype(np.float32)
      if not np.all(np.isfinite(action)):
        raise UnsafeTiltError("policy returned a non-finite action")
      last_action = action

      target = default_pos.copy()
      target[perm] = default_pos[perm] + action_scale * action
      target = target + joint_trim_rad
      target = np.array([C.clamp_q(j, float(target[i]))
                         for i, j in enumerate(C.SIM_ORDER)], np.float32)
      if slew_rad_s > 0:
        step = slew_rad_s * dt
        target = cmd + np.clip(target - cmd, -step, step)
      cmd = target
      tracking_error = cmd - q
      if marching:
        tracking_errors.append(tracking_error.copy())

      bus.write_goals(C.goal_counts(cmd, calib))
      bus.tick(dt)
      sample_sim_feet(float(gait[1]), marching)
      base_position = bus.base_position()
      if base_position is None:
        base_position = np.full(3, np.nan, np.float32)
      base_heading = bus.base_heading()
      if base_heading is None:
        base_heading = np.nan
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

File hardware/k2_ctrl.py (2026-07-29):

#!/usr/bin/env python3
"""K2 controller. Same code drives MuJoCo or the real servo chain.

    python -m hardware.k2_ctrl --bus sim --motion squat --viewer
    python -m hardware.k2_ctrl --bus /dev/ttyAMA0 --motion squat

The only thing --bus changes is which object implements the count-level servo
interface. Observation building, calibration, clamping, slew limiting and the
control rate are identical on both paths, so a motion that behaves in sim is
running byte-identical logic on hardware.

Safety on the real robot: goals are clamped to the joint limits and to counts
[40, 4055], slew-limited, and the run always ends with torque released.
Ctrl-C goes limp rather than freezing at the last goal.
"""

from __future__ import annotations

import argparse
import signal
import sys
import time

import numpy as np

from . import k2_conventions as C
from . import k2_bus, k2_motion

RATE_HZ = 50.0
SLEW_RAD_S = 1.5        # max commanded joint speed
APPROACH_S = 3.0        # time to ease from the current pose into the start pose


def build_obs(q, qd, last_action, extra=()):
    """The observation vector, built identically for sim and real."""
    return np.concatenate([q, qd, np.asarray(extra, np.float32), last_action])


def slew(prev, target, dt, limit=SLEW_RAD_S):
    step = limit * dt
    return prev + np.clip(target - prev, -step, step)


def _calibration(bus):
    """Sim is perfectly calibrated by construction; hardware must be measured."""
    if isinstance(bus, k2_bus.SimBus):
        return C.default_calibration()
    calib = C.load_calibration()
    if calib is None:
        # Never silently fall back to home_raw=2048 on hardware. The real home
        # counts run from 1370 to 2337, so the default would command every
        # joint tens of degrees off -- up to 60 on hip_roll_L.
        raise SystemExit(
            f"No calibration at {C.CALIB_PATH}\n"
            f"Run:  python -m hardware.k2_calibrate\n"
            f"(a calibration saved under Robot_v2_single_leg is NOT used)")
    missing = [j for j in C.SIM_ORDER
               if j not in calib.get("home_raw", {})
               or j not in calib.get("sign", {})]
    if missing:
        raise SystemExit(f"calibration is missing joints: {missing}")
    return calib


def _write_log(log, rows, stabilizer):
    """Persist collected telemetry, including data preceding a safety stop."""
    if log is None or not rows:
        return
    header = "t," + ",".join(f"cmd_{j}" for j in C.SIM_ORDER) + "," \
             + ",".join(f"q_{j}" for j in C.SIM_ORDER) + "," \
             + ",".join(f"qd_{j}" for j in C.SIM_ORDER)
    if stabilizer is not None:
        header += (",imu_roll,imu_pitch,imu_roll_rate,imu_pitch_rate,"
                   "feedback_roll,feedback_pitch")
    np.savetxt(log, np.array(rows), delimiter=",", header=header, comments="")
    print(f"wrote {log}")


def run(bus, traj, heights, dt, verbose=True, log=None,
        attitude=None, stabilizer=None, approach_s=APPROACH_S):
    """Play a joint trajectory, closing the loop through the bus each tick."""
    calib = _calibration(bus)

    pos, _ = bus.read_pos_speed()
    q_now = C.q_vector(pos, calib)

    # Ease from wherever the robot actually is into the first pose, so nothing
    # snaps when torque comes on.
    n_appr = int(float(approach_s) / dt)
    approach = np.stack([q_now + (traj[0] - q_now) * (0.5 * (1 - np.cos(np.pi * i / n_appr)))
                         for i in range(n_appr)])

    cmd = q_now.copy()
    rows = []
    feedback_ticks = 0
    t_start = time.perf_counter()
    for phase, seq in (("approach", approach), ("motion", traj)):
        for i, target in enumerate(seq):
            pos, spd = bus.read_pos_speed()
            q = C.q_vector(pos, calib)
            qd = C.qd_vector(spd, calib)

            if stabilizer is not None:
                if attitude is None:
                    raise ValueError("stabilizer requires an attitude source")
                gyro, gravity = (attitude.attitude()
                                 if isinstance(bus, k2_bus.SimBus)
                                 else attitude.attitude(dt))
                # Fade feedback in over one second instead of stepping the
                # servos when the complementary filter first initializes.
                gain_scale = min(1.0, (feedback_ticks + 1) * dt)
                try:
                    target = stabilizer.update(
                        target, gyro, gravity, dt, gain_scale=gain_scale)
                except BaseException:
                    # UnsafeTiltError is raised before the current tick can be
                    # appended. Preserve every completed sample for diagnosis.
                    _write_log(log, rows, stabilizer)
                    raise
                feedback_ticks += 1

            cmd = slew(cmd, target, dt)
            bus.write_goals(C.goal_counts(cmd, calib))
            bus.tick(dt)

            if log is not None:
                # Log wall-clock, not the nominal tick count: a loop that
                # cannot hold the rate is otherwise invisible in the CSV.
                row = [time.perf_counter() - t_start]
                row.extend(cmd)
                row.extend(q)
                row.extend(qd)
                if stabilizer is not None:
                    s = stabilizer.last_state
                    row.extend([s["roll"], s["pitch"],
                                s["roll_rate"], s["pitch_rate"],
                                s["roll_correction"], s["pitch_correction"]])
                rows.append(row)
            if verbose and phase == "motion" and i % 25 == 0:
                err = np.abs(q - cmd).max()
                extra = ""
                if isinstance(bus, k2_bus.SimBus):
                    extra = (f"  base {bus.base_height()*1000:6.1f}mm "
                             f"(want {heights[i]*1000:6.1f})")
                print(f"  t={i*dt:5.2f}s  knee_R={np.degrees(q[3]):+6.1f}deg  "
                      f"max|q-cmd|={np.degrees(err):5.2f}deg{extra}")
                if stabilizer is not None and stabilizer.last_state is not None:
                    s = stabilizer.last_state
                    print(f"       IMU roll={np.degrees(s['roll']):+5.1f}deg "
                          f"pitch={np.degrees(s['pitch']):+5.1f}deg  "
                          f"correction=({np.degrees(s['roll_correction']):+4.1f},"
                          f"{np.degrees(s['pitch_correction']):+4.1f})deg")

    n_ticks = len(approach) + len(traj)
    elapsed = time.perf_counter() - t_start
    print(f"  {n_ticks} ticks in {elapsed:.2f}s "
          f"= {n_ticks/elapsed:.1f} Hz achieved (target {1/dt:.0f} Hz, "
          f"nominal {n_ticks*dt:.2f}s)")
    if elapsed > n_ticks * dt * 1.05:
        print("  NOTE: the loop could not hold the target rate")

    _write_log(log, rows, stabilizer)
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

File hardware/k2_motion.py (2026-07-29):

"""Scripted motions for K2, generated from the model rather than hand-tuned.

The squat is solved as inverse kinematics on the MJCF: for a given knee bend,
find the hip and ankle angles that keep both soles flat on the ground, the
feet level with each other, and the centre of mass over the middle of the
support polygon. Solving against the model means the trajectory stays correct
if the CAD changes.

Only the sagittal joints move (hip_pitch, knee, ankle_pitch); hip_roll, hip_yaw
and the v4 ankle_roll all stay at zero.
"""

from __future__ import annotations

import numpy as np

from . import k2_conventions as C

# Solved with both feet planted, so this needs no IMU: the ground closes the
# kinematic chain and the encoders alone determine the base pose.
#
# Keep the first hardware squat deliberately shallow. The current v4 MJCF has
# enough ankle range for this 35 deg check without approaching a hard stop.
MAX_KNEE_DEG = 35.0

# Reachable base-link height envelope measured from the current v4 MJCF.
MAX_BASE_H = 0.308    # feet-flat straight-knee solution
MIN_BASE_H = 0.300    # feet-flat solution at MAX_KNEE_DEG


def _model():
    import mujoco
    model = mujoco.MjModel.from_xml_path(str(C.MJCF))
    return model, mujoco.MjData(model)


class SquatIK:
    """Flat-foot double-support squat poses."""

    def __init__(self):
        import mujoco
        self.mj = mujoco
        self.model, self.data = _model()
        self.qadr = {j: self.model.jnt_qposadr[
            mujoco.mj_name2id(self.model, mujoco.mjtObj.mjOBJ_JOINT, m)]
            for j, m in C.JOINT_TO_MJCF.items()}
        self.sites = {s: mujoco.mj_name2id(self.model, mujoco.mjtObj.mjOBJ_SITE, s)
                      for s in ("right_foot", "left_foot")}
        # v4: the sole moved off the ankle onto the new ankle-roll "Feet" body.
        self.bodies = {b: mujoco.mj_name2id(self.model, mujoco.mjtObj.mjOBJ_BODY, b)
                       for b in ("Feet_right", "Feet_left", "base_link")}
        self._heel_toe = {
            "Feet_right": self._sole_points("right_foot_collision", "Feet_right"),
            "Feet_left": self._sole_points("left_foot_collision", "Feet_left"),
        }

    def _sole_points(self, gname, bname):
        """Heel and toe of the sole, in that ankle's own frame.

        Two explicit points turn 'sole on the ground' and 'sole flat' into
        plain z==0 constraints, with no assumption about which body axis
        points forward -- the ankle's local X actually runs along world -Y.
        """
        self.mj.mj_resetData(self.model, self.data)
        self.mj.mj_forward(self.model, self.data)
        gid = self.mj.mj_name2id(self.model, self.mj.mjtObj.mjOBJ_GEOM, gname)
        bid = self.bodies[bname]
        mid = self.model.geom_dataid[gid]
        v = self.model.mesh_vert[self.model.mesh_vertadr[mid]:
                                 self.model.mesh_vertadr[mid]
                                 + self.model.mesh_vertnum[mid]]
        w = v @ self.data.geom_xmat[gid].reshape(3, 3).T + self.data.geom_xpos[gid]
        sole = w[w[:, 2] < w[:, 2].min() + 0.002]
        R, p = self.data.xmat[bid].reshape(3, 3), self.data.xpos[bid]
        return (R.T @ (sole[sole[:, 0].argmin()] - p),
                R.T @ (sole[sole[:, 0].argmax()] - p))
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

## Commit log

2026-08-16 Marching working
    [K2_joint_stl_map.xlsx]
2026-08-16 Working walking config
    [k2_physics.xml]
2026-08-21 Somehow working f/b/yaw 2026-08-20_22-33-23_turn_v1_from_bidir_iter2700/turn_v1_iter2900.onnx
2026-08-22 Working symmetry code turn_v9_iter3499.onnx
    [k2_physics.xml]
